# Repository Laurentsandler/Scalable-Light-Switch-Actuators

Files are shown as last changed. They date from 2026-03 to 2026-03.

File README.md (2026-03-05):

# Scalable Light Switch Actuators

Small battery-powered automatic light switch actuators powered by ESP32.

## Description

A solution for renters who cannot install smart light switches. These small, battery-powered actuators mount on the outside of existing light switches and physically toggle them using a servo motor. They connect together over ESP-NOW (no Wi-Fi needed per module) via a central base station that handles Blynk/HomeKit integration. Up to 20 modules can be controlled from one base station, due to EspNow restrictions

## My Motivation

I live in a rented house, so I cannot install smart light switches. The only solutions on the market are bulky actuators that use a proprietary remote and don't support smart home platforms like Amazon Alexa, Home Assistant, Zigbee, or Apple HomeKit. So I decided to build my own using a custom PCB.

## Hardware Design

The custom PCB was designed using EasyEDA. The PCB dimensions are 32 × 26 mm — fitting perfectly on the back of an SG90 servo.

EasyEda project link:
https://easyeda.com/editor#id=|93ad15a1b7dc47d78bf5fa35e29b968b|5e4b051ffabf4bad87d0927d44e92544|834b59119eae41c79e7f3501ccd5901a|6ec8a34cbfa545fb97d85c115d355580|78c27b5c97ff48638fb5b9d93af4b543|2bb35249ba30405cbe0a014a9d109027|e6663c2f617c42289e6e439fa6266942

### PCB Layout & 3D Renders





### Case

The case was designed in Onshape — as small as possible while fitting all components, with a snap-on lid and space for wires.




## Onshape project link: https://cad.onshape.com/documents/06b28d6b3b71f47cc2911267/w/042815538e1a38e5d56684fa/e/e83a82b9ce472ea6086be9af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

### 3d mockups






## Features

- **Servo Control**: Physically toggles light switches ±20° via SG90 servo
- **ESP-NOW**: Low-power mesh-style communication between modules and base station — no per-module Wi-Fi needed
- **Blynk Integration**: Control up to 5 switches via Blynk virtual pins V0–V4
- **Apple HomeKit / BLE**: Supported via ESPHome/Matter on the ESP32-C3
- **Long Battery Life**: ~2 months per module using deep sleep + ESP-NOW architecture
- **USB-C Charging**: On-board battery charging and power path management
- **Physical Button**: User can still manually toggle the switch via button on the device
- **Compact PCB**: 32 × 26 mm, fits on the back of an SG90 servo
- **Snap-fit 3D Printed Case**: Designed in Onshape, easily printable

## System Architecture

```
[Blynk App] → [Base ESP32 (WiFi)]            --ESP-NOW--> [Module 1 (ESP32-C3)] → Servo 1
                                             --ESP-NOW--> [Module 2 (ESP32-C3)] → Servo 2
                                             --ESP-NOW--> [Module 3 (ESP32-C3)] → Servo 3
                                             --ESP-NOW--> [Module 4 (ESP32-C3)] → Servo 4
                                             --ESP-NOW--> [Module 5 (ESP32-C3)] → Servo 5
```

## Software Dependencies

Install these libraries via Arduino IDE Library Manager:
- WiFi (built-in)
- ESP-NOW (built-in)
- BlynkSimpleEsp32 (Blynk library)
- ESP32Servo

## Configuration

### Module Setup
1. Flash each ESP32-C3 module with the Module firmware
2. Note the MAC address printed on Serial for each module
3. Paste the MAC addresses into the Base firmware

### Base Setup
Edit the following in `Firmware/base/base.ino`:

```cpp
const char* WIFI_SSID = "YOUR_WIFI_SSID";
const char* WIFI_PASS = "YOUR_WIFI_PASSWORD";
const char* BLYNK_AUTH = "YOUR_BLYNK_AUTH_TOKEN";

uint8_t module1MAC[] = {0x00, 0x00, 0x00, 0x00, 0x00, 0x00}; // Replace with actual MACs
uint8_t module2MAC[] = {0x00, 0x00, 0x00, 0x00, 0x00, 0x00};
// ... etc
```

## Usage

### Blynk App Setup
1. Create a new Blynk project
2. Add 5 Button widgets on virtual pins **V0–V4**
3. Set each button to **Push mode**, Integer **0/1**
4. Each V0–V4 button controls Module 1–5 respectively

## API Services Used

- **Blynk**: Remote switch control (V0–V4)
- **ESP-NOW**: Local wireless communication between base and modules

## BOM

| ID | Name | Designator | Footprint | Quantity | Manufacturer Part | Manufacturer | Supplier | Supplier Part | Price | Pins | 3D Model | Contributor | JLCPCB Part Class | Value | Link |
|----|---|---|---|---|---|---|---|---|---|---|---|---|---|---|---|
| 1 | 10uF | C1,C5,C8,C9 | C0603 | 4 | CL10A106KP8NNNC | SAMSUNG | LCSC | C19702 | 0.007 | 2 | C0603_L1.6-W0.8-H0.8 | lcsc | Basic Part | | https://item.szlcsc.com/362304.html |
| 2 | 100nF | C4,C6 | C0603 | 2 | CC0603KRX7R9BB104 | YAGEO | LCSC | C14663 | 0.002 | 2 | C0603_L1.6-W0.8-H0.8 | lcsc | Basic Part | | https://item.szlcsc.com/362304.html |
| 3 | 1uF | C7 | C0805 | 1 | CL21B105KBFNNNE | SAMSUNG | LCSC | C28323 | 0.01 | 2 | C0805_L2.0-W1.3-H1.3 | lcsc | Basic Part | | https://item.szlcsc.com/373011.html |
| 4 | B2B-PH-K-S(LF)(SN) | CN1 | CONN-TH_B2B-PH-K-S | 1 | B2B-PH-K-S(LF)(SN) | JST | LCSC | C131337 | 0.031 | 2 | CONN-TH_PH2.00-LI-2P | LCSC | Extended Part | | https://item.szlcsc.com/142630.html |
| 5 | B5819W_C8598 | D1 | SOD-123_L2.7-W1.6-LS3.7-RD-1 | 1 | B5819W SL | CJ | LCSC | C8598 | 0.024 | 2 | SOD-123_L2.7-W1.6-LS3.7-RD-1 | lcsc | Basic Part | | https://atta.szlcsc.com/upload/public/pdf/source/20210423/C2828417_EF1BF8BE3D48F97E320B09B073C89160.pdf |
| 6 | AO3401A | Q1 | SOT-23_L2.9-W1.3-P1.90-LS2.4-BR | 1 | AO3401A | AOS | LCSC | C15127 | 0.057 | 3 | SOT-23-3P_L2.9-W1.3-H1.0-LS2.4-P0.95 | lcsc | Basic Part | | https://item.szlcsc.com/236142.html |
| 7 | 5.1kΩ | R1,R2 | R0603 | 2 | 0603WAF5101T5E | UNI-ROYAL | LCSC | C23186 | 0.001 | 2 | R0603 | lcsc | Basic Part | | https://www.mouser.in/datasheet/2/447/PYu_RT_1_to_0_01_RoHS_L_11-1669912.pdf |
| 8 | 100kΩ | R3 | R0603 | 1 | 0603WAF1003T5E | UNI-ROYAL | LCSC | C25803 | 0.001 | 2 | R0603 | lcsc | Basic Part | | https://www.mouser.in/datasheet/2/447/PYu_RT_1_to_0_01_RoHS_L_11-1669912.pdf |
| 9 | 2kΩ | R4 | R0603 | 1 | 0603WAF2001T5E | UNI-ROYAL | LCSC | C22975 | 0.001 | 2 | R0603 | lcsc | Basic Part | | https://www.mouser.in/datasheet/2/447/PYu_RT_1_to_0_01_RoHS_L_11-1669912.pdf |
| 10 | 10kΩ | R5,R6,R7,R8 | R0603 | 4 | 0603WAF1002T5E | UNI-ROYAL | LCSC | C25804 | 0.001 | 2 | R0603 | lcsc | Basic Part | | https://www.mouser.in/datasheet/2/447/PYu_RT_1_to_0_01_RoHS_L_11-1669912.pdf |
| 11 | TS-1088-AR02016 | SW1,SW2 | SW-SMD_L3.9-W3.0-P4.45 | 2 | TS-1088-AR02016 | XUNPU | LCSC | C720477 | 0.048 | 2 | SW-SMD_L3.9-W2.9-H2.0-LS4.8 | LCSC | Basic Part | | https://item.szlcsc.com/457636.html |
| 12 | TP4054A | U1 | SOT-23-5_L2.9-W1.6-P0.95-LS2.8-TL | 1 | TP4054A | YONGYUTAI | LCSC | C33551022 | 0.031 | 5 | SOT-23-5_L2.9-W1.6-P0.95-LS2.8-TL | lcsc | Extended Part | | https://item.szlcsc.com/2162298.html |
| 13 | ESP32-C3-WROOM-02-N4(4MB) | U5 | BULETM-SMD_ESPRESSIF_ESP32-C3-WROOM-02-N4-4MB | 1 | ESP32-C3-WROOM-02-N4 | ESPRESSIF | LCSC | C2934560 | 3.067 | 27 | BULETM-SMD_ESPRESSIF_ESP32-C3-WROOM-02-N4-4MB | LCSC | Extended Part | | https://atta.szlcsc.com/upload/public/pdf/source/20220106/F07459EFFE1D7CBA94B4FB8A075146A6.pdf |
| 14 | CH340N_C2977777 | U6 | SOP-8_L4.9-W3.9-P1.27-LS6.0-BL | 1 | CH340N | WCH | LCSC | C2977777 | 0.561 | 8 | SOP-8_L4.9-W3.9-P1.27-LS6.0-BL-1 | LCSC | Extended Part | | https://item.szlcsc.com/383602.html |
| 15 | TPS73633DBVR | U7 | SOT-23-5_L3.0-W1.7-P0.95-LS2.8-BR | 1 | TPS73633DBVR | TI | LCSC | C28038 | 0.422 | 5 | SOT-23-5_L2.9-W1.6-H1.1-LS2.8-P0.95 | lcsc | Extended Part | | https://item.szlcsc.com/236104.html |
| 16 | TYPE-C-31-M-12 | USBC1 | USB-C_SMD-TYPE-C-31-M-12_1 | 1 | TYPE-C-31-M-12 | 韩国韩荣 | LCSC | C165948 | 0.183 | 16 | USB-C_SMD-TYPE-C-31-M-12_1 | LCSC | Extended Part | | https://item.szlcsc.com/datasheet/TYPE-C-31-M-12/177331.html |
| 17 | R0603 | R9 | R0603 | 1 | 0603WAD1001T5E | UNI-ROYAL | LCSC | C51218 | 0.007 | 2 | R0603 | lcsc | Extended Part | 1kΩ | https://lcsc.com/eda_search?q=C51218&%26type=1&ref=editor |
| 18 | LED0805-R-RD | LED2 | LED0805-R-RD | 1 | 17-215UYC/S530-A3/TR8 | EVERLIGHT | LCSC | C72036 | 0.054 | 2 | LED0805-RD | lcsc | Extended Part | | https://lcsc.com/eda_search?q=C72036&%26type=1&ref=editor |
| 19 | SG90 Micro Servo Motor 9G | | N/A | 5 | SG90 | SopwMap | Amazon | B0DP3VG59G | 11.99 | 3 | | | | | https://www.amazon.com/dp/B0DP3VG59G |
| 20 | 582728 400mAh 3.7V LiPo Battery | | N/A | 1 | 582728 | Rainbow Battery Store | AliExpress | 1005007648840057 | 5.31 | 2 | | | | | https://www.aliexpress.com/item/1005007648840057.html |
| 21 | ESP32 DevKitC WIFI+Bluetooth Development Board (ESP32-32U) | | N/A | 1 | ESP32-32U | YouKeyi Store | AliExpress | 1005008949552110 | 5.09 | | | | | https://www.aliexpress.com/item/1005008949552110.html |

## License

MIT License

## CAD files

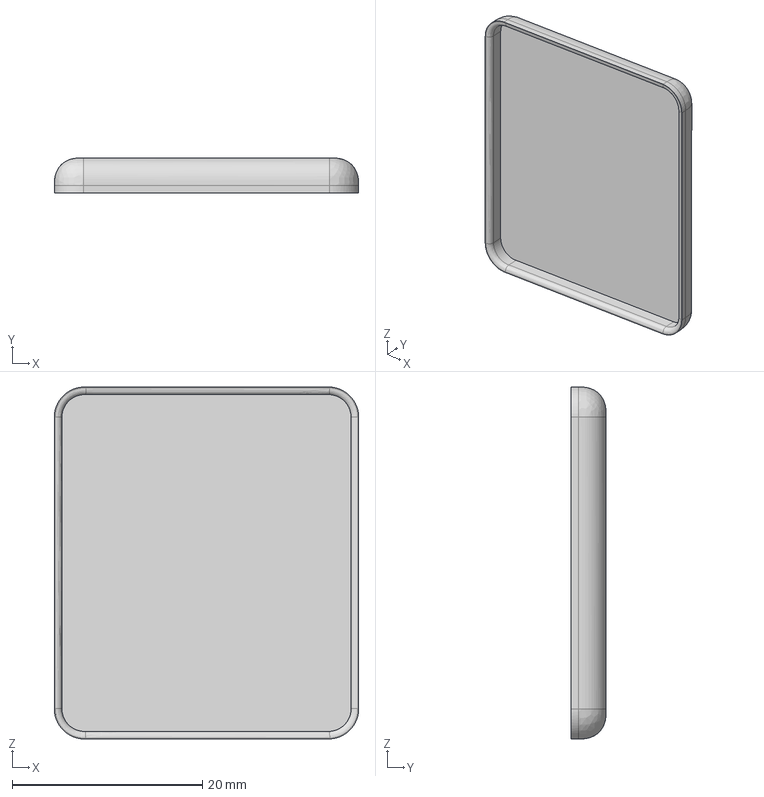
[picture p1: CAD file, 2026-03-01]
CAD/Lid.step
32.0 x 3.70 x 37.0 mm

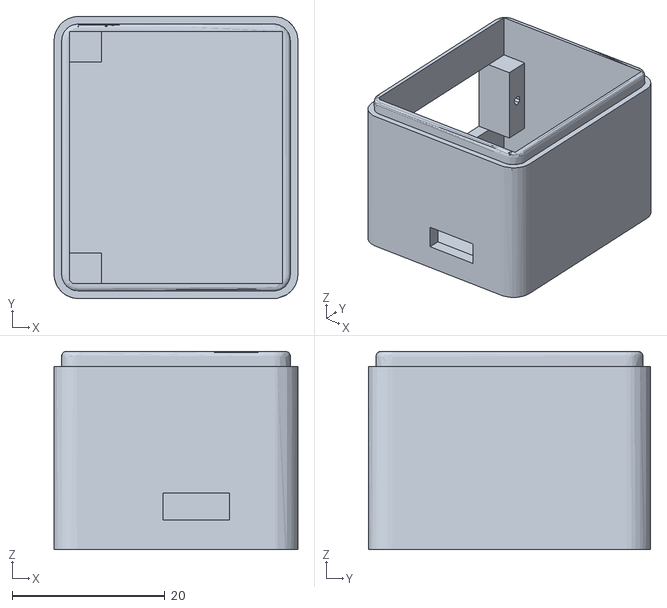
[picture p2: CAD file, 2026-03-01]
CAD/Shiny Turing.stl
32.0 x 37.0 x 26.0

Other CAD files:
CAD/Lid.stl

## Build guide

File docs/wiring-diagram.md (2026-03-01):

# Wiring Diagram

This document describes the hardware connections for the Scalable Light Switch Actuator modules.

## Module Connections (ESP32-C3 PCB)

### SG90 Servo
The servo wires are soldered directly to pads on the bottom of the PCB next to the USB-C port.

```
Servo Wire  →  PCB Pad
----------------------
Red (VCC)   →  5V / VBAT
Brown (GND) →  GND
Orange (PWM)→  GPIO5
```

### Physical Button
```
Button      →  ESP32-C3 Pin
----------------------------
One side    →  GPIO9
Other side  →  GND
(INPUT_PULLUP mode - no external resistor needed)
```

### USB-C (Charging & Programming)
- USB-C port on PCB is used for both **charging the battery** and **programming the ESP32-C3** via the on-board CH340 USB-serial chip.

### Battery
- LiPo battery connects via JST connector on the PCB
- Charging is handled by the on-board charging IC
- Power path management automatically switches between USB-C power and battery

## Base Station Connections

The base station is a standard ESP32 dev board connected to USB power (always-on).

```
ESP32 Dev Board  →  Power
--------------------------
USB              →  Wall adapter (always on)
```

No additional wiring needed — the base station communicates wirelessly via ESP-NOW.

## PCB Block Diagram

```
USB-C ──► [Power Path IC] ──► 3.3V Rail ──► ESP32-C3
              │                              │
              ▼                              ├──► CH340 (USB-Serial)
         [Charger IC]                        ├──► Button (GPIO9)
              │                              └──► Servo PWM (GPIO5)
              ▼
          [LiPo Battery]
```

## Notes

- PCB dimensions: 32 × 26 mm
- All SMD components for compact form factor
- The PCB mounts directly on the back of the SG90 servo

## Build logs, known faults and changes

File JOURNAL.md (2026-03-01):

<!--
  This journal is auto generated by Hack Club Blueprint.
-->

# 2/20/2026 11 AM - Building the Concept and Setting Goals

_Time spent: 1.0h_

I have a problem which I am sure many other people do. I live in a rented out house, so we cannot install our own smart light switches. And the only other solution on the market is actuators that you put on the outside that move your light switch with remote. And they are very, very bulky. And don't support smart home like Amazon Alexa, Home Assistant, Zigbee, etc. They only use a remote. So I've decided to build my own. Using a custom PCB. Here are some goals:

- small and easy to install
- long battery life
- works with apple homekit, and blynk
- easy to charge with a charging dock
- User is still able to use light switch through a button on the device
- cost effective
- uses esp-now to connect switches together in no wifi areas of the home

Once I had these goals set, I made some sketches of how it would work and how it would look.

There are two versions which I came up with on how the PCB and server should be located. One where the servo sits on the PCB and the battery on top and another one where the board takes up the back of the servo, and the servo sits on it, and then the battery is off to the side.

I chose to do a combination of both, where I have the PCB take up only the footprint of the servo, and the servo will sit on the PCB. Then the battery will sit on the PCB too and take up the same footprint and be off to the side.

---

# 2/20/2026 12 PM - Choosing an ESP32 module

_Time spent: 0.3h_

I eventually settled on the ESP32-C3-WROOM-02 because:

- **Low power**: Efficient RISC-V core, ~5 µA deep sleep, ideal for wake → move servo → sleep cycles.
- **Compact**: ~18 × 20 mm module, fits easily under/behind a servo.
- **Wi-Fi + BLE built-in**: Supports ESP-NOW; BLE enables HomeKit (via ESPHome/Matter), provisioning, and future Matter support.
- **Cost-effective**: Cheaper than S3 and significantly less than WROVER modules.

---

# 2/22/2026 - Building Schematic

_Time spent: 5.3h_

Before starting on the schematic, I needed to set some rules for it. I need to make sure that the finished PCB can support battery charging. Power path management so it is able to switch to USB-C power when it is plugged in and to charge the battery and step down 5 V to 3.7 V for the ESP32. As well as a USB to serial converter for the ESP32. All while being very small. I split the design into six main components:

1. Battery charging and power management
2. Power path management circuit
3. USB-C power input
4. Voltage regulation
5. USB to serial
6. Physical buttons in ESP32

I went through multiple iterations of the schematic before arriving at the final design.

---

# 2/23/2026 - Creating PCB

_Time spent: 5.5h_

My PCB needed to be really small and fit onto the back of an SG90 servo. So I chose the dimensions 32 by 26 mm. This fits perfectly onto the back of the servo. I separated the board into two main sections:

- **High power section** where 5 V comes in from USB-C, gets stepped down to 3.3 V and charges the battery.
- **ESP32 and buttons and CH340 chip**

There are three points to solder each of the three servo wires on the bottom next to the USB-C port.

---

# 2/25/2026 1:23 PM - Finding a suitable battery

_Time spent: 1.0h_

I needed to find a high capacity battery that stored a lot of energy while fitting behind the footprint of the servo and the PCB.

I found a battery that fits directly behind the footprint of the PCB and servo.

Now let's talk about battery life. This is very important.

- If I have each module connected to Wi-Fi, then my battery life will look like one or two days.
- But if I have a master ESP32 that's always plugged into the wall, that manages connections between Blynk, and then when Blynk sends a request, the ESP32 that's plugged into the wall sends an ESP-NOW request to one of the slave modules, then I will have about **two months of battery life** per module.

---

# 2/25/2026 1:27 PM - Deciding on an ESP-NOW ESP32 base station module

_Time spent: 0.3h_

To keep prices down and since this base station isn't really concerned about space, I will just choose a dev module with a good antenna that comes with it, which will communicate over ESP-NOW to each of the modules that will be stuck onto the light switches.

I found a good module which is inexpensive and has plenty of compute power and a good antenna attached to it.

---

# 2/28/2026 - Creating the case

_Time spent: 3.0h_

I designed a small case in Onshape. I had a few criteria for the case:

1. It had to be as small as possible while still fitting all of the components, and space for some wires to connect the battery and servo to the PCB.
2. It had to be easily printable, and have a lid that snaps on.

The case fits the PCB, battery, and servo with room for wiring. The red block in the mockup represents the battery.

**Files added:**
- `Case.stl`
- `Case lid.stl`
- Case mockup images in the Images folder

---

# 3/1/2026 - Writing the code

_Time spent: 2.5h_

Today I wrote the firmware for each of the modules and the ESP32 base station.

The base ESP32 connects to WiFi/Blynk and talks to 5 ESP32-C3 modules over ESP-NOW. When you press a Blynk button (V0–V4), the base sends a toggle command to the matching module, which moves its servo ±20° to flip a light switch.

**To set it up:**

1. Flash each C3 module with the corresponding "Module" code and note the MAC address it prints on serial
2. Paste those MACs into the "base code" along with your WiFi and Blynk credentials
3. Flash the base ESP32 with "Base" code
4. In Blynk, create 5 button widgets on V0–V4 (Push mode, Integer 0/1)

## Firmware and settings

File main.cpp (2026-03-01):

/*
 * ============================================================
 *  ESP32-C3 Light Switch Module – ESP-NOW Servo Controller
 * ============================================================
 *  Receives toggle commands from the base station over ESP-NOW
 *  and moves the servo ±N degrees to flip a physical light switch.
 *
 *  Flash the SAME sketch to all 5 modules – each one is
 *  identified automatically by its unique MAC address.
 * ============================================================
 */

#include <WiFi.h>
#include <esp_now.h>
#include <esp_wifi.h>
#include <ESP32Servo.h>

// ========================  CONFIGURABLE  ========================

// --- Servo ---
#define SERVO_PIN           14       // GPIO connected to servo signal
#define SERVO_CENTER        90       // Neutral / center angle (degrees)
#define SERVO_MOVE_DEGREES  20       // Degrees to move per toggle

// Servo pulse range (adjust for your exact servo if needed)
#define SERVO_MIN_US        500
#define SERVO_MAX_US        2400

// --- ESP-NOW ---
#define ESPNOW_CHANNEL      1       // Must match the base station

// --- Base station MAC (optional – used to filter senders) ---
//     Set to all zeros to accept commands from any sender.
uint8_t baseMac[6] = {0x00, 0x00, 0x00, 0x00, 0x00, 0x00};
#define FILTER_SENDER false          // set true to only accept from baseMac

// --- Servo movement limits ---
#define SERVO_MIN_ANGLE     0
#define SERVO_MAX_ANGLE     180

// ========================  END CONFIGURABLE  ====================

// --- Command packet (must match base definition) ---
typedef struct {
  uint8_t  moduleId;
  int16_t  moveDegrees;
  uint8_t  toggleCmd;
} __attribute__((packed)) CmdPacket;

// --- Globals ---
Servo myServo;
int currentAngle  = SERVO_CENTER;   // start at center
int direction     = 1;               // +1 or -1, flips each toggle

// ----------------------------------------------------------------
//  Move servo to a target angle (clamped to safe range)
// ----------------------------------------------------------------
void moveServo(int targetAngle) {
  // Clamp
  if (targetAngle < SERVO_MIN_ANGLE) targetAngle = SERVO_MIN_ANGLE;
  if (targetAngle > SERVO_MAX_ANGLE) targetAngle = SERVO_MAX_ANGLE;

  Serial.printf("[SERVO] Moving %d° → %d°\n", currentAngle, targetAngle);
  myServo.write(targetAngle);
  currentAngle = targetAngle;
}

// ----------------------------------------------------------------
//  Handle toggle: move ±degrees, flip direction for next call
// ----------------------------------------------------------------
void handleToggle(int16_t degrees) {
  int target = currentAngle + (degrees * direction);
  moveServo(target);
  direction *= -1;   // reverse for next press
}

// ----------------------------------------------------------------
//  ESP-NOW receive callback
// ----------------------------------------------------------------
void onDataRecv(const esp_now_recv_info_t *info, const uint8_t *data, int len) {
  // Optional sender filter
  if (FILTER_SENDER) {
    bool match = true;
    for (int i = 0; i < 6; i++) {
      if (info->src_addr[i] != baseMac[i]) { match = false; break; }
    }
    if (!match) {
      Serial.println("[ESP-NOW] Ignored – sender not base station");
      return;
    }
  }

  if (len < (int)sizeof(CmdPacket)) {
    Serial.printf("[ESP-NOW] Packet too short (%d bytes)\n", len);
    return;
  }

  CmdPacket pkt;
  memcpy(&pkt, data, sizeof(pkt));

  Serial.printf("[ESP-NOW] Received – module:%d  degrees:%d  toggle:%d\n",
    pkt.moduleId, pkt.moveDegrees, pkt.toggleCmd);

  if (pkt.toggleCmd == 1) {
    handleToggle(pkt.moveDegrees > 0 ? pkt.moveDegrees : SERVO_MOVE_DEGREES);
  }
}

// ----------------------------------------------------------------
//  Setup
// ----------------------------------------------------------------
void setup() {
  Serial.begin(115200);
  delay(1000);
  Serial.println("\n=== ESP32-C3 Light Switch Module ===");

  // --- Servo ---
  myServo.setPeriodHertz(50);
  myServo.attach(SERVO_PIN, SERVO_MIN_US, SERVO_MAX_US);
  myServo.write(SERVO_CENTER);
  Serial.printf("[SERVO] Attached on GPIO %d – center %d°\n", SERVO_PIN, SERVO_CENTER);

  // --- WiFi (station mode, no connection – just for ESP-NOW) ---
  WiFi.mode(WIFI_STA);
  WiFi.disconnect();            // make sure we're not connected to an AP
  esp_wifi_set_channel(ESPNOW_CHANNEL, WIFI_SECOND_CHAN_NONE);

  // Print MAC so you can paste it into the base sketch
  Serial.printf("[INFO] Module MAC: %s  ← paste this into base sketch\n",
    WiFi.macAddress().c_str());

  // --- ESP-NOW ---
  if (esp_now_init() != ESP_OK) {
    Serial.println("[ERR] ESP-NOW init failed!");
    ESP.restart();
  }
  esp_now_register_recv_cb(onDataRecv);

  Serial.println("Setup complete – waiting for commands…\n");
}

// ----------------------------------------------------------------
//  Loop
// ----------------------------------------------------------------
void loop() {
  // Nothing to do – all work happens in the ESP-NOW callback.
  delay(10);
}

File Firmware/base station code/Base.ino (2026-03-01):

/*
 * ============================================================
 *  ESP32 Base Station – Blynk + ESP-NOW Light Switch Controller
 * ============================================================
 *  Connects to WiFi / Blynk and relays virtual-pin button
 *  presses to remote ESP32-C3 modules over ESP-NOW.
 *  Each module drives a servo to toggle a physical light switch.
 * ============================================================
 */

#include <WiFi.h>
#include <esp_now.h>
#include <esp_wifi.h>
#include <BlynkSimpleEsp32.h>

// ========================  CONFIGURABLE  ========================

// --- WiFi / Blynk credentials ---
#define WIFI_SSID           "YOUR_WIFI_SSID"
#define WIFI_PASS           "YOUR_WIFI_PASSWORD"
#define BLYNK_TEMPLATE_ID   "YOUR_TEMPLATE_ID"
#define BLYNK_TEMPLATE_NAME "LightActuator"
#define BLYNK_AUTH_TOKEN    "YOUR_BLYNK_AUTH_TOKEN"

// --- Number of modules (max 20 for ESP-NOW peer limit) ---
#define NUM_MODULES 5

// --- Servo movement in degrees each toggle ---
#define SERVO_MOVE_DEGREES 20

// --- ESP-NOW channel (must match modules) ---
#define ESPNOW_CHANNEL 1

// --- Virtual pins mapped to each module (V0 → module 0, etc.) ---
//     Blynk buttons should be set to "Switch" mode (0/1).
#define VPIN_MODULE_0  V0
#define VPIN_MODULE_1  V1
#define VPIN_MODULE_2  V2
#define VPIN_MODULE_3  V3
#define VPIN_MODULE_4  V4

// --- MAC addresses of the 5 ESP32-C3 modules ---
//     Replace with the actual MAC of each module.
//     Run the module sketch once and check Serial for its MAC.
uint8_t moduleMacs[NUM_MODULES][6] = {
  {0xAA, 0xBB, 0xCC, 0xDD, 0xEE, 0x01},   // Module 0
  {0xAA, 0xBB, 0xCC, 0xDD, 0xEE, 0x02},   // Module 1
  {0xAA, 0xBB, 0xCC, 0xDD, 0xEE, 0x03},   // Module 2
  {0xAA, 0xBB, 0xCC, 0xDD, 0xEE, 0x04},   // Module 3
  {0xAA, 0xBB, 0xCC, 0xDD, 0xEE, 0x05},   // Module 4
};

// ========================  END CONFIGURABLE  ====================

// --- Command packet sent over ESP-NOW ---
typedef struct {
  uint8_t  moduleId;       // which module (0-4)
  int16_t  moveDegrees;    // signed degrees to move
  uint8_t  toggleCmd;      // 1 = toggle the switch
} __attribute__((packed)) CmdPacket;

// Track send status
volatile bool lastSendOk = false;

// ----------------------------------------------------------------
//  ESP-NOW send callback
// ----------------------------------------------------------------
void onDataSent(const uint8_t *mac, esp_now_send_status_t status) {
  lastSendOk = (status == ESP_NOW_SEND_SUCCESS);
  Serial.printf("[ESP-NOW] Send to %02X:%02X:%02X:%02X:%02X:%02X – %s\n",
    mac[0], mac[1], mac[2], mac[3], mac[4], mac[5],
    lastSendOk ? "OK" : "FAIL");
}

// ----------------------------------------------------------------
//  Register all module peers
// ----------------------------------------------------------------
void registerPeers() {
  for (int i = 0; i < NUM_MODULES; i++) {
    esp_now_peer_info_t peer = {};
    memcpy(peer.peer_addr, moduleMacs[i], 6);
    peer.channel = ESPNOW_CHANNEL;
    peer.encrypt = false;

    if (esp_now_add_peer(&peer) == ESP_OK) {
      Serial.printf("[ESP-NOW] Peer %d registered: %02X:%02X:%02X:%02X:%02X:%02X\n",
        i, moduleMacs[i][0], moduleMacs[i][1], moduleMacs[i][2],
        moduleMacs[i][3], moduleMacs[i][4], moduleMacs[i][5]);
    } else {
      Serial.printf("[ESP-NOW] FAILED to register peer %d\n", i);
    }
  }
}

// ----------------------------------------------------------------
//  Send toggle command to a specific module
// ----------------------------------------------------------------
void sendToggle(uint8_t moduleIndex) {
  if (moduleIndex >= NUM_MODULES) {
    Serial.printf("[ERR] Module index %d out of range\n", moduleIndex);
    return;
  }

  CmdPacket pkt;
  pkt.moduleId   = moduleIndex;
  pkt.moveDegrees = SERVO_MOVE_DEGREES;
  pkt.toggleCmd  = 1;

  esp_err_t result = esp_now_send(moduleMacs[moduleIndex],
                                   (uint8_t *)&pkt, sizeof(pkt));
  if (result == ESP_OK) {
    Serial.printf("[CMD] Toggle sent to module %d\n", moduleIndex);
  } else {
    Serial.printf("[CMD] Error sending to module %d: %d\n", moduleIndex, result);
  }
}

// ----------------------------------------------------------------
//  Blynk virtual-pin handlers  (button press → toggle module)
// ----------------------------------------------------------------
BLYNK_WRITE(VPIN_MODULE_0) {
  if (param.asInt() == 1) sendToggle(0);
}

BLYNK_WRITE(VPIN_MODULE_1) {
  if (param.asInt() == 1) sendToggle(1);
}

BLYNK_WRITE(VPIN_MODULE_2) {
  if (param.asInt() == 1) sendToggle(2);
}

BLYNK_WRITE(VPIN_MODULE_3) {
  if (param.asInt() == 1) sendToggle(3);
}

BLYNK_WRITE(VPIN_MODULE_4) {
  if (param.asInt() == 1) sendToggle(4);
}

// ----------------------------------------------------------------
//  Setup
// ----------------------------------------------------------------
void setup() {
  Serial.begin(115200);
  delay(1000);
  Serial.println("\n=== ESP32 Base Station ===");

  // --- WiFi ---
  WiFi.mode(WIFI_AP_STA);   // AP+STA needed for ESP-NOW alongside WiFi
  WiFi.begin(WIFI_SSID, WIFI_PASS);

  Serial.print("Connecting to WiFi");
  int tries = 0;
  while (WiFi.status() != WL_CONNECTED && tries < 40) {
    delay(500);
    Serial.print(".");
    tries++;
  }

  if (WiFi.status() == WL_CONNECTED) {
    Serial.printf("\nWiFi connected – IP: %s\n", WiFi.localIP().toString().c_str());
  } else {
    Serial.println("\nWiFi FAILED – Blynk will not work, but ESP-NOW will still run.");
  }

  // Force the STA interface to the ESP-NOW channel so peers line up
  esp_wifi_set_channel(ESPNOW_CHANNEL, WIFI_SECOND_CHAN_NONE);

  // Print own MAC (useful for debugging)
  Serial.printf("Base MAC (STA): %s\n", WiFi.macAddress().c_str());

  // --- ESP-NOW ---
  if (esp_now_init() != ESP_OK) {
    Serial.println("[ERR] ESP-NOW init failed!");
    ESP.restart();
  }
  esp_now_register_send_cb(onDataSent);
  registerPeers();

  // --- Blynk ---
  Blynk.config(BLYNK_AUTH_TOKEN);
  Blynk.connect(5000);   // non-blocking 5 s timeout

  Serial.println("Setup complete.\n");
}

// ----------------------------------------------------------------
//  Loop
// ----------------------------------------------------------------
void loop() {
  Blynk.run();
}

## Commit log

2026-03-01 Add Bill of Materials section to README and create BOM CSV file
    [BOM Final Actuator Mar 2026.csv]
2026-03-01 Rename Shiny Turing (1).stl to Lid.stl
    [Lid.stl]
2026-03-01 Rename Case (2).step to Lid.step
    [Lid.step]
2026-03-01 Remove hardware requirements and BOM from README
    Removed hardware requirements and BOM sections to streamline documentation.
2026-03-01 Update BOM with manufacturer details and links
    Updated manufacturer names and added links for components.
    [BOM Final Actuator Mar 2026.csv]
2026-03-01 Revise BOM Final Actuator Mar 2026 format
    Updated BOM file to include a new format with headers and links.
    [BOM Final Actuator Mar 2026.csv]
2026-03-01 Revise BOM format and add new information
    Updated BOM with new columns for Footprint, Manufacturer, and additional details.
    [BOM Final Actuator Mar 2026.csv]
2026-03-03 Add SG90 Micro Servo Motor 9G to all BOMs
    [BOM Final Actuator Mar 2026.csv]
2026-03-05 Add BOM.csv file
    [BOM.csv]
